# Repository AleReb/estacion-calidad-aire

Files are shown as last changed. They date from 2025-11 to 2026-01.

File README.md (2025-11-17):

# Estación Multiparamétrica de Calidad del Aire

La estación integra sensores **electroquímicos**, **ópticos** y **meteorológicos** en una estructura vertical compacta. El sistema recolecta, almacena y transmite datos **en tiempo casi real**, lo que permite correlacionar calidad del aire y condiciones meteorológicas. Actualmente se encuentra en construcción con pruebas de campo; todos los sensores cuentan con especificaciones validadas y se calibran antes de entrar en operación.

## Características destacadas
- Soporte tipo torre de 2–5 m con exposición 360° y altura de medición a 1,5 m sobre nivel del suelo.
- Alimentación autónoma mediante panel solar y banco de baterías.
- Comunicaciones GSM/4G complementadas con almacenamiento local en microSD.
- Plataforma única con sensores sincronizados y módulos accesibles para reemplazo rápido.
- Incluye colectores para muestreo pasivo de material particulado sedimentable (conforme a Resolución Exenta N° 1449 del MMA, 2023).

## Sensores integrados
| Tipo | Modelo | Rango / Límite | Precisión / Resolución | Tecnología |
| --- | --- | --- | --- | --- |
| PM1.0/2.5/10 | Plantower PMS5003ST | 1 µg/m³ (límite) | ±1 µg/m³ | Óptico láser |
| O₃ | Alphasense OX-B431 | 1 ppb (límite) | ±1 ppbv | Amperométrico |
| NO₂ | Alphasense NO2-B43F | 1 ppb (límite) | ±1 ppbv | Amperométrico |
| CO | Alphasense CO-B4 | 1 ppm (límite) | ±1 ppmv | Amperométrico |
| NO | Alphasense NO-B4 | 1 ppb (límite) | ±1 ppbv | Amperométrico |
| CO₂ | Winsen MH-Z19B/MH-Z19C | 1 ppm (resolución) | — | Infrarrojo NDIR |
| VOC (totales) | Winsen ZE40A-TVOC | 0–2 ppm | 0.01 ppm | PID/MOS |
| SO₂ | Alphasense SO2-B4 (objetivo) | 5 ppb (error) | — | Electroquímico |
| Meteo (T, HR, P, VV, DV, precipitación, radiación, UV, luz) | ComWinTop CWT-UWD-SDTHAPSIR / CWT-UR-S | Según ficha | Ver ficha | RS485 (Modbus) |

## Aplicaciones
- Monitoreo ciudadano y municipal.
- Validación de sensores de bajo costo.
- Correlación con estaciones de referencia.
- Evaluación de impactos urbanos o industriales.

## Guía rápida del repositorio
- `01-requisitos-interesados/`: necesidades y casos de uso basados en el brochure técnico.
- `02-requisitos-sistema/`: requisitos funcionales/no funcionales y especificaciones (contaminantes, soporte meteo, emergentes).
- `03-diseño-arquitectura/`: decisiones, vistas de arquitectura y espacio para diagramas.
- `04-diseño-detallado/`: definición preliminar de hardware, firmware y gestión de datos.
- `05-implementacion/`: árbol para hardware (PCB, carcasas, componentes), firmware (PlatformIO) y software (backend/frontend/scripts).
- `06-10/`: integración, verificación, validación, despliegue y operación/mantenimiento.
- `documentacion/`, `datos/`, `herramientas/`, `configuracion/`: repositorios para datasheets, datasets EPA/WMO, utilidades y perfiles de configuración.
- `gestion-proyecto/planificacion/roles-responsabilidades.md`: lista actualizada de cargos, incluyendo QA/QC y administración de datos.

## Índice de informes y manuales
| Recurso | Ubicación | Descripción |
| --- | --- | --- |
| Manual ISB/AFE y notas de aplicación Alphasense | [`documentacion/datasheets-sensores/sensores-gases/electroquimicos/alphasense/`](documentacion/datasheets-sensores/sensores-gases/electroquimicos/alphasense/) | PDFs AAN-803-05, manual ISB y guía rápida de placas que convierten corriente a voltaje para sensores B4/B43F. |
| Tutorial offsets WEe/AEe | [`documentacion/manuales-tecnicos/calibracion/tutorial-offsets-wee-aee.md`](documentacion/manuales-tecnicos/calibracion/tutorial-offsets-wee-aee.md) | Procedimiento paso a paso para medir offsets electrónicos en placas ISB/AFE con multímetro. |
| Nota técnica AAN-803-05 | [`documentacion/manuales-tecnicos/calibracion/AAN-803-05.pdf`](documentacion/manuales-tecnicos/calibracion/AAN-803-05.pdf) | Referencia oficial del fabricante para calibraciones electroquímicas. |
| Brochure y ficha de operación en terreno | [`documentacion/manuales-tecnicos/operacion/brochure.pdf`](documentacion/manuales-tecnicos/operacion/brochure.pdf) · [`documentacion/manuales-tecnicos/operacion/Ficha Terreno AIRE.pdf`](documentacion/manuales-tecnicos/operacion/Ficha%20Terreno%20AIRE.pdf) | Ficha de despliegue en terreno y brochure visual del proyecto. |
| Reporte laboratorio – voltaje circuito abierto ISB | [`documentacion/informes-pruebas/laboratorio/condiciones-controladas/Volt_Circuito_abierto_ISB_alphasense_est05/Voltage_circuito_abierto_alphasense_estacion_5.pdf`](documentacion/informes-pruebas/laboratorio/condiciones-controladas/Volt_Circuito_abierto_ISB_alphasense_est05/Voltage_circuito_abierto_alphasense_estacion_5.pdf) | Informe LaTeX con fotos e instrumental para medición de voltaje en placas ISB. Incluye fuentes `.tex` e imágenes en `img/`. |
| Reporte campo – co-ubicación SINCA | [`documentacion/informes-pruebas/campo/co-ubicacion-sinca/calibracion-sinca-1.pdf`](documentacion/informes-pruebas/campo/co-ubicacion-sinca/calibracion-sinca-1.pdf) | Evidencia PDF de campaña de co-ubicación para calibraciones con red SINCA. |

## Equipo de trabajo
| Rol | Responsable | Función principal |
| --- | --- | --- |
| Dirección del proyecto | Zoe Fleming | Define lineamientos estratégicos, asegura recursos y relación con interesados de alto nivel. |
| Coordinación general | Luis Gómez | Coordina disciplinas, consolida reportes de avance y comunica el estado del proyecto. |
| Firmware y comunicaciones | Alejandro Rebolledo | Lidera programación de firmware, integración de sensores y enlaces GSM/4G/RS485. |
| Operaciones en terreno | Pablo Ortiz | Gestiona despliegues de torres, logística de instalación y soporte en campo. |
| Mediciones y administración de datos | Catalina Azola | Define rutinas de muestreo, resguarda datos de mediciones y entrega datasets a QA/QC. |
| Documentación regulatoria, QA/QC y bases de datos | Christopher Silva | Mantiene cumplimiento normativo, verifica calidad de datos y gestiona respaldos/registros. |
| Diseño de hardware y componentes | Rodrigo Ortega | Diseña la estructura física, integra panel solar + baterías y define componentes mecánicos. |
| Diseño electrónico | Sebastián Adonay | Desarrolla la electrónica de adquisición y acondicionamiento para sensores electroquímicos, ópticos y meteorológicos. |

## Cómo colaborar (incluye uso con Codex)
1. Clona este repositorio y revisa el README antes de abrir Codex.
2. Abre una sesión de Codex desde la raíz (`codex run`), y revisa los archivos en `gestion-proyecto/planificacion/` para conocer roles y tareas pendientes.
3. Documenta nuevas decisiones en la carpeta correspondiente (por ejemplo, requisitos → `02-...`, hardware → `04-diseño-detallado/...`).
4. Añade contenidos reales en los documentos vacíos; si no existe información todavía, deja una nota explícita indicando que está pendiente (mantén el estilo usado hasta ahora).
5. Usa `.gitkeep` para conservar directorios vacíos si agregas nuevos subcontenidos.
6. Antes de hacer commit, ejecuta `git status` para revisar qué archivos cambiaste y organiza los mensajes de commit por área (requisitos, arquitectura, firmware, etc.).

## Contacto
Proyecto en desarrollo: **Estación Multiparamétrica de Monitoreo Ambiental**  \
Contacto: [luis.gomez@udd.cl](mailto:luis.gomez@udd.cl)

## Descargo de Responsabilidad

El código y la documentación de este proyecto se ofrecen "tal cual", sin garantías de ningún tipo, expresas o implícitas. El uso de este material es bajo su propio riesgo. Los autores no se hacen responsables de ningún daño o pérdida que pueda surgir de su uso.

## Licencia

Este proyecto está licenciado bajo la **Creative Commons Attribution-NonCommercial 4.0 International (CC BY-NC 4.0)**.



Usted es libre de:
-   **Compartir** — copiar y redistribuir el material en cualquier medio o formato.
-   **Adaptar** — remezclar, transformar y construir sobre el material.

Bajo los siguientes términos:
-   **Atribución** — Debe dar crédito de manera adecuada, proporcionar un enlace a la licencia, e indicar si se han realizado cambios.
-   **NoComercial** — No puede utilizar el material para una finalidad comercial.

Para ver una copia de esta licencia, visite [http://creativecommons.org/licenses/by-nc/4.0/](http://creativecommons.org/licenses/by-nc/4.0/) o consulte el archivo [LICENSE](LICENSE) en este repositorio.

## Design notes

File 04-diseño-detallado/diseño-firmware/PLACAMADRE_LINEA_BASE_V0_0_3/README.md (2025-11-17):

# Firmware Placa Madre Línea Base v0.0.3

Este directorio contiene el código fuente del firmware para la placa de monitoreo ambiental "Placa Madre Rev. D", basada en un microcontrolador ESP32.

## Descripción General

El firmware está diseñado para operar como un sistema de monitoreo ambiental autónomo y robusto. Se encarga de recolectar datos de una amplia gama de sensores, almacenarlos localmente en una tarjeta SD y transmitirlos periódicamente a un servidor remoto a través de una red celular (GSM/LTE). Además, integra la capacidad de capturar y enviar imágenes desde una cámara externa.

## Características Principales

-   **Adquisición de Datos Multi-Sensor:** Integra y lee datos de sensores analógicos y digitales a través de I2C, UART y RS485.
-   **Almacenamiento Local:** Guarda todas las mediciones y los registros de errores en formato CSV en una tarjeta SD para redundancia y análisis posterior.
-   **Comunicaciones Celulares:** Utiliza un módem SIM7600 para enviar datos de sensores e imágenes a un servidor web mediante peticiones HTTP (GET y POST).
-   **Gestión de Cámara Externa:** Controla una cámara conectada por puerto serie para solicitar, recibir y almacenar imágenes.
-   **Robustez y Estabilidad:** Implementa un Watchdog Timer (WDT) para reiniciarse automáticamente en caso de bloqueo. Incluye una máquina de estados para reiniciar el módem si falla repetidamente.
-   **Gestión de Energía:** Controla la alimentación de periféricos como la cámara y el módem para optimizar el consumo.
-   **Interfaz de Depuración:** Ofrece un conjunto de comandos a través del puerto serie para facilitar la depuración y el control manual de funciones clave.
-   **Feedback Visual:** Utiliza un LED RGB (NeoPixel) para indicar el estado del sistema (inicio, éxito, error, etc.).

## Hardware y Librerías Clave

-   **Microcontrolador:** ESP32
-   **Módem:** SIMCom SIM7600 (`TinyGsmClient`)
-   **Sensores Analógicos:** Múltiples `Adafruit_ADS1115` para gases (NO₂, CO, O₃, NO, SO₂).
-   **Sensores Digitales:**
    -   `MHZ19` (CO₂) por UART.
    -   `PMS5003` (Material Particulado) por UART.
    -   Estación Meteorológica y Sensor UV por RS485 (`ModbusMaster`).
    -   Sensor TVOC/SO₂ externo por I2C.
-   **Reloj en Tiempo Real:** `RTC_DS3231` para timestamping preciso.
-   **Almacenamiento:** Tarjeta MicroSD.
-   **Cámara:** Dispositivo externo controlado por UART.

## Estructura del Código y Módulos

El proyecto está modularizado en varios archivos `.ino` para una mejor organización:

-   `PLACAMADRE_LINEA_BASE_V0_0_3.ino`: Archivo principal. Contiene la lógica de `setup()` y `loop()`, la inicialización de todos los periféricos y la orquestación de las tareas principales (leer, guardar, enviar).
-   `sensores.ino`: Agrupa todas las funciones dedicadas a la lectura de los diferentes sensores (ADCs, Modbus, I2C, UART).
-   `datalogger.ino`: Gestiona todas las operaciones de escritura en la tarjeta SD, incluyendo la creación de archivos CSV para datos y logs, y la función para añadir registros.
-   `gsm.ino`: Contiene toda la lógica de comunicación con el módem SIM7600. Esto incluye el envío de comandos AT, la conexión a la red GPRS, el envío de datos por HTTP y la máquina de estados para reiniciar el módem.
-   `cam.ino`: Implementa el protocolo de comunicación serie para solicitar y recibir imágenes de la cámara externa, gestionando la recepción por trozos y los reintentos.
-   `rtc.ino`: Funciones para la gestión del reloj DS3231, incluyendo la sincronización de la hora a partir de la red celular.
-   `neopixel.ino`: Controla el LED RGB para proporcionar feedback visual del estado del sistema.
-   `serialComands.ino`: Define una interfaz de comandos a través del monitor serie para depuración.
-   `auxiliar.ino`: Contiene funciones de ayuda, como la que imprime el motivo del último reinicio del ESP32.
-   `web.ino`: (Actualmente desactivado en el código principal) Implementa un servidor web a través de un punto de acceso WiFi para gestionar los archivos de la SD de forma remota.

## Lógica Operacional

El `loop()` principal opera en base a temporizadores no bloqueantes (`millis()`) y una máquina de estados simple controlada por banderas (`bools`):

1.  **Lectura de Sensores (`leyendoDatos`):** Cada 20 segundos, se leen todos los sensores y se actualizan las variables globales.
2.  **Guardado en SD (`savedSD`):** Cada 60 segundos, se construye una línea de CSV con los últimos datos leídos y se guarda en la tarjeta SD.
3.  **Envío de Datos (`sending`):** Cada 5 minutos, se envían los últimos datos al servidor remoto a través de una petición HTTP GET.
4.  **Gestión de Fotos (`requestedfoto`):** Cada 3 horas, se solicita una foto a la cámara, se recibe, se guarda en la SD y se envía al servidor a través de una petición HTTP POST.

## Comandos de Depuración por Puerto Serie

Conectado a 115200 baudios, puedes usar los siguientes comandos:

-   `h`: Muestra la lista de comandos.
-   `s`: Envía la última foto capturada al servidor.
-   `t`: Sincroniza el reloj RTC con la hora de la red celular.
-   `c`: Enciende la cámara y solicita una foto.
-   `d`: Envía los datos de los sensores al servidor.
-   `e`: Inicia un ciclo de reinicio de energía para el módem.
-   `f`: Simula un error de transmisión para probar el contador de fallos del módem.
-   `g`: Realiza un test de la SIM y actualiza la información de la red.

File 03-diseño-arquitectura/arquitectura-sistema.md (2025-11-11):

# Arquitectura del sistema

## Soporte físico
- Torre entre 2 y 5 metros con exposición 360°.
- Altura de medición establecida en 1,5 metros sobre el nivel del suelo.

## Energía
- Alimentación mediante panel solar y banco de baterías para operación autónoma.

## Comunicaciones y almacenamiento
- Transmisión principal por GSM/4G.
- Respaldo local a través de microSD.

## Integración de sensores
- Sensores electroquímicos (Alphasense serie B4/B43F) para O₃, NO₂, CO y NO.
- Sensor óptico láser Plantower PMS5003ST para PM₁.₀, PM₂.₅ y PM₁₀.
- Sensores adicionales: CO₂ (Winsen MH-Z19B/MH-Z19C), VOC totales (Winsen ZE40A-TVOC) y SO₂ (Alphasense SO2-B4, en definición).
- Estación meteorológica digital RS485 (ComWinTop CWT-UWD-SDTHAPSIR y CWT-UR-S).

## Soporte a muestreo pasivo
- Colectores de material particulado sedimentable ajustados a la Resolución Exenta N° 1449 del MMA (2023).

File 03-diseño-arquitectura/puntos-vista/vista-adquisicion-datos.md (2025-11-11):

# Vista de adquisición de datos
- Los sensores están sincronizados en una plataforma única para asegurar series temporales consistentes.
- Los datos se almacenan localmente en microSD y se transmiten por GSM/4G casi en tiempo real.
- La altura de medición (1,5 m) y la torre de 2–5 m mantienen condiciones homogéneas durante la adquisición.

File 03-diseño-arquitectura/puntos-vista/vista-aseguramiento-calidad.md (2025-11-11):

# Vista de aseguramiento de calidad
- Todos los sensores cuentan con especificaciones validadas y se calibran previamente a su operación.
- La estación incluye equipos de muestreo pasivo de material particulado sedimentable conforme a Resolución Exenta N° 1449 (MMA, 2023) para contrastar datos.
- El brochure advierte que CO y SO₂ pueden ubicarse cerca del límite de detección en entornos urbanos; se monitorean para eventos significativos, lo que condiciona los planes de QA/QC.

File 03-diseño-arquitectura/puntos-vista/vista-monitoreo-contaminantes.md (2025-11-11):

# Vista de monitoreo de contaminantes
- Sensores capturan PM₁.₀, PM₂.₅ y PM₁₀ mediante Plantower PMS5003ST (límite 1 µg/m³, precisión ±1 µg/m³).
- Gases criterio O₃, NO₂, CO y NO se monitorean con la serie Alphasense B4/B43F con límites de 1 ppb (1 ppm para CO).
- Los sensores se encuentran en una estructura vertical compacta con exposición 360° para captar eventos urbanos e industriales.

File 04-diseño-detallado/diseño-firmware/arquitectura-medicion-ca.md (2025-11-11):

# Arquitectura de medición de calidad del aire
- El firmware integra lecturas de sensores electroquímicos (O₃, NO₂, CO, NO), ópticos (PM₁.₀/PM₂.₅/PM₁₀) y meteorológicos RS485.
- Todos los canales se sincronizan para entregar datos en tiempo casi real, cumpliendo el objetivo del brochure.

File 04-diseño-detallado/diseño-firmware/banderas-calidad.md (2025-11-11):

# Banderas de calidad
El brochure solo indica que los sensores se calibran previamente y cuentan con especificaciones validadas; no se entregan definiciones de banderas. Esta sección quedará pendiente hasta contar con reglas de QA/QC detalladas.

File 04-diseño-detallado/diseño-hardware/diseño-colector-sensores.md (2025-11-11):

# Diseño del colector de sensores
- Estructura vertical compacta montada en torre de 2–5 m con exposición 360°.
- Módulos accesibles para mantenimiento rápido según la configuración descrita en el brochure.
- Integración física de sensores electroquímicos (Alphasense), ópticos (PMS5003ST) y meteorológicos (ComWinTop RS485) en un solo soporte para garantizar sincronización.

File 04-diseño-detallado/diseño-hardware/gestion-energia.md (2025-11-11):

# Gestión de energía
- Alimentación mediante panel solar con banco de baterías, tal como se declara en la configuración del sistema.
- El esquema autónomo soporta la operación continua del datalogger, las comunicaciones GSM/4G y los sensores meteorológicos RS485.

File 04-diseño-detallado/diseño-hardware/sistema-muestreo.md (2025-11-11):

# Sistema de muestreo
- Altura de captación de 1,5 m sobre nivel del suelo para alinearse con la exposición definida.
- Colectores para material particulado sedimentable compatibles con Resolución Exenta N° 1449 (MMA, 2023).
- Sensores ópticos y electroquímicos ubicados en flujo controlado dentro del colector para mantener la precisión declarada (±1 µg/m³ para PM, ±1 ppbv para O₃/NO₂/NO).

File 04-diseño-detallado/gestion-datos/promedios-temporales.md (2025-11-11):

# Promedios temporales
El material disponible no detalla ventanas de promedio (minutal, horario, diario). Se debe completar cuando se definan los procesos de reporte.

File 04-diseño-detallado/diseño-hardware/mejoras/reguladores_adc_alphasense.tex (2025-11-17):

\documentclass[a4paper, 12pt]{article}

% --- PAQUETES BÁSICOS ---
\usepackage[utf8]{inputenc}
\usepackage[T1]{fontenc}
\usepackage[spanish]{babel} % Para soporte de idioma español
\usepackage{amsmath} % Para símbolos matemáticos (ge, mu, le, approx, etc.)
\usepackage{amssymb} % Para más símbolos
\usepackage[margin=1in]{geometry} % Para márgenes
\usepackage{textcomp} % Para I²C
\usepackage{graphicx} % Para imágenes (aunque no se usan aquí)

% --- PAQUETE DE HIPERVÍNCULOS ---
\usepackage{hyperref}
\hypersetup{
    colorlinks=true,
    linkcolor=blue,
    filecolor=magenta,      
    urlcolor=blue, % Color de los links
    pdftitle={Reguladores de alto PSRR y ADC de alta resolución para sensores Alphasense},
    pdfpagemode=FullScreen,
}

% --- TÍTULO ---
\title{Reguladores de alto PSRR y ADC de alta resolución para sensores Alphasense}
\author{} % Ocultar autor
\date{} % Ocultar fecha

% --- INICIO DEL DOCUMENTO ---
\begin{document}

\maketitle

Para obtener mediciones precisas con sensores de gas electroquímicos Alphasense (ej. OX-B431, NO2-B43F), es crucial proporcionarles una alimentación muy estable y leer su salida analógica con suficiente resolución.

A continuación se presentan opciones de reguladores lineales de alto rechazo de ruido (PSRR) para filtrar el ruido de la fuente de 5V/12V (proveniente de conversión DC-DC), junto con convertidores ADC de $\ge 12$ bits de resolución, de bajo ruido y con interfaz digital (I²C/SPI) adecuadas para las salidas analógicas de estos sensores.

\section*{Reguladores lineales de alto PSRR y bajo ruido}

Los siguientes reguladores ofrecen alto rechazo de rizado ($>70$dB) en frecuencias medias/altas y baja interferencia, facilitando una alimentación limpia (3.5-6.4 V DC) para las placas acondicionadoras (ISB) de los sensores Alphasense\textsuperscript{1, 2}. Todos son componentes compactos (montaje en PCB) con documentación disponible, y muchos se pueden encontrar en AliExpress u otras tiendas:

\begin{itemize}
    \item \textbf{Microchip MCP1754/MCP1755} Regulador CMOS LDO de 150 mA, rango de entrada 3.6-16V y salida fija o ajustable hasta 5.5 V. Destaca por PSRR $>70$ dB @1 kHz\textsuperscript{3} y baja corriente quiescente ($\sim 56~\mu$A). Dropout típico de 300 mV @150 mA, con ruido de salida muy bajo. Disponible en encapsulados SOT-23, SOT-223, etc., fácil de integrar\textsuperscript{4}. Precio aprox. $< 1$ USD por unidad.

    \item \textbf{Diodes Inc. AP7387} Nueva familia de LDO 5-60 V in, 150 mA out. Combina PSRR $\sim 70$ dB @1 kHz con ultra bajo consumo (2 $\mu$A)\textsuperscript{5}. Viene en versiones de salida fija comunes (3.3V, 5.0V, etc., $\pm 2\%$ precisión)\textsuperscript{6}. Ideal para alimentar desde baterías de 12V o 24V, minimizando el ruido de conversores previos. Encapsulados SOT23/SOT89 (de 3 a 5 pines), muy compactos y económicos ($\sim 0,3$ USD en volúmenes\textsuperscript{7}).

    \item \textbf{STMicroelectronics LDO40L} LDO automotriz 38 V max in, 400 mA out. Posee PSRR de 70 dB @1 kHz y ruido ultra bajo ($\sim 20~\mu\text{V}_{\text{RMS}}$ referido a Vout)\textsuperscript{8}. Soporta salida fija (3.3V, 5V, etc.) o ajustable hasta 11V, con dropout $\le 140$ mV @400 mA\textsuperscript{9}. Encapsulado DFN6 (3x3 mm). Aunque requiere cuidado de soldado, ofrece alta estabilidad y protección interna (limitación de corriente y térmica)\textsuperscript{8}. Aprox. 1-2 USD.

    \item \textbf{TI TPS7A4700/TPS7A47} - Regulador LDO ultra bajo ruido de Texas Instruments, soporta entrada hasta 36 V, salida 1.4-20V (1 A máx). Ofrece solo $4~\mu\text{V}_{\text{RMS}}$ de ruido en banda 10-100 kHz\textsuperscript{10} y mantiene PSRR alto ($\approx 78$ dB @1 kHz) e incluso $\sim 74$ dB a 1 MHz\textsuperscript{11}. Incluye filtro de ruido (pin NR) para optimizar la limpieza de salida. Viene en QFN-20 o MSOP-8 exponenciado; es un componente profesional (usado en instrumentación de alta precisión y audio)\textsuperscript{12}. Precio ~3-5 USD. Recomendado si se busca máxima filtración de ruido de conmutación.

    \item \textbf{Analog Devices LT3042} - LDO de referencia para aplicaciones RF/análogas sensibles. Entrada 1.8-20 V, salida hasta 15V (200 mA). Presenta PSRR excepcional ($\approx 79$dB @1MHz) y ruido ínfimo ($\sim 0.8~\mu\text{V}_{\text{RMS}}$) gracias a su arquitectura de alta ganancia\textsuperscript{11}. Requiere pocos componentes externos (resistor de programación y capacitores), pero viene en MSOP/DFN de 10 pines. Es viable para lograr una línea de 5 V muy limpia a partir de 12V con carga ligera (los módulos ISB consumen $\sim 1$ mA cada uno\textsuperscript{13, 14}). Su disponibilidad puede ser limitada, pero hay módulos en AliExpress que incorporan el LT3042 listos para usar (orientados a audio Hi-Fi), alrededor de 10-15 USD.
\end{itemize}

Nota: Se debe evitar el uso de reguladores comunes como LM7805, LM317 o AMS1117 para esta aplicación sin filtros adicionales, ya que su PSRR cae en frecuencias altas, pudiendo dejar pasar ruido de switching. Los reguladores anteriores destacan por mantener un rechazo elevado más allá de la región audible, asegurando que el ruido del convertidor DC-DC (ej. rizado de cientos de kHz) no introduzca variaciones en la señal del sensor. Asimismo, se recomienda agregar capacitores de filtrado de alta frecuencia (cerámicos de 0.1 $\mu$F cerca de la entrada/salida) e incluso filtros $\pi$ o LC si el ruido de la fuente es muy agresivo.

\section*{ADCs de alta resolución y bajo ruido $(I^2C/SPI)$}

Las salidas analógicas de los sensores Alphasense (a través del tablero ISB) son señales de muy baja amplitud y pueden variar solo unos pocos milivoltios o menos según la concentración de gas. Para capturarlas con precisión, se requieren ADC externos de alta resolución ($\ge 12$ bits) y bajo nivel de ruido. A continuación, algunas opciones populares (disponibles como chips o módulos en AliExpress) para leer estas señales, idealmente en configuración diferencial (para restar el electrodo auxiliar) y con interfaz digital sencilla:

\begin{itemize}
    \item \textbf{Texas Instruments ADS1115} - ADC 16 bits, 4 canales (o 2 diferenciales) con I²C. Es ampliamente utilizado por su facilidad y precisión: proporciona 16-bit efectivos hasta 860 muestras/segundo vía I²C\textsuperscript{15}. Incluye PGA programable (ganancia hasta x16) para amplificar señales débiles y aprovechar todo el rango\textsuperscript{15}. Opera entre 2.0-5.5 V. Es perfecto para estos sensores - de hecho, se emplea en placas comerciales para Alphasense (Smart Citizen Kit) para leer múltiples sensores de gas\textsuperscript{16, 17}. Se consigue como módulo de 4 canales ($\sim 3-5$ USD en marketplaces) o en IC SSOP. Su ruido interno es bajo: a ganancia máxima ($\pm 0.256$ V rango) cada bit $\approx 7.8~\mu$V, logrando 15 bits libres de ruido a baja velocidad\textsuperscript{18, 19}, suficiente para resolver variaciones de pocos ppb en concentración.

    \item \textbf{Microchip MCP3424} Convertidor Delta-Sigma de 18 bits, 4 canales diferencial (I²C). Ofrece resolución seleccionable (12/14/16/18 bits) y velocidades de conversión de 240 SPS (12-bit) hasta 3.75 SPS (18-bit)\textsuperscript{20}. Incluye un PGA de x1-x8 y autocalibración interna de offset/ganancia en cada conversión\textsuperscript{21}, útil para medir señales muy débiles con alta exactitud. Funciona de 2.7-5.5V. Es reconocido como ADC de "bajo ruido y alta precisión" dentro de su familia\textsuperscript{21}. Disponible en módulos breakout (ej. DFRobot Fermion, alrededor de 10-15 USD) y también en versiones de 2 canales (MCP3422) si se requieren menos entradas. Ideal cuando se busca mayor resolución que 16-bit a costo razonable.

    \item \textbf{TI / Waveshare ADS1256} ADC 24 bits, 8 canales (SPI) para quienes necesiten la máxima resolución. Es un ADC sigma-delta de alta precisión con referencia interna de 2.5 V, muy utilizado en placas de adquisición de datos. Soporta hasta 30 kSPS de salida y puede configurarse en 8 entradas sencillas o 4 diferenciales\textsuperscript{22, 23}. A 24 bits puede resolver microvoltios, capturando incluso fluctuaciones muy pequeñas de la señal del sensor. Funciona a 5 V e incluye un regulador de referencia de bajo ruido (ADR03) en las placas comerciales\textsuperscript{24}. Módulos basados en ADS1256 se encuentran en AliExpress/Amazon ($\sim 20$ USD) ya montados, con interfaz SPI lista para conectar a un microcontrolador. Son adecuados si se requiere registrar niveles de ppb con mínima incertidumbre, aunque implican más complejidad de software y consumo.

    \item \textbf{Otras opciones:} Si el presupuesto o la complejidad son factores, existen ADCs más sencillos de 12-16 bits que pueden servir. Por ejemplo, el ADS1015 (hermano menor del ADS1115, 12 bits a 3.3 kSPS, I²C) o los MCP3008/MCP3208 (SAR ADC de 10/12 bits, SPI de 8 canales). No ofrecen el mismo nivel de ruido ultra-bajo que los sigma-delta anteriores, pero pueden ser suficientes para aplicaciones menos exigentes.
\end{itemize}

En general, para sensores de gases traza donde las variaciones de señal son muy pequeñas, conviene priorizar ADC de sigma-delta con alta resolución y filtrado digital, incluso si su velocidad es menor, ya que los sensores Alphasense tienen respuesta en escala de segundos.

Referencias específicas: Alphasense recomienda un diseño de electrónica de bajo ruido para alcanzar resoluciones de 15 ppb\textsuperscript{25, 2}. Por ello, combinar un buen regulador LDO (como los anteriores) - que asegure una alimentación de 5V limpia y estable para la placa ISB junto con un ADC de alta resolución ($16+$ bits) por I²C/SPI, permitirá explotar al máximo la precisión de estos sensores. En la práctica, desarrollos como la placa Smart Citizen ASB utilizan dos ADS1115 de 16-bit para leer hasta 8 canales analógicos Alphasense\textsuperscript{16, 17}, demostrando la viabilidad de estas soluciones con componentes disponibles en el mercado.

Cada componente mencionado incluye documentación detallada del fabricante y suele estar disponible en plataformas como AliExpress, eBay o distribuidores (a veces como módulos listos para usar), facilitando su integración en un diseño personalizado.

\section*{Referencias}

\begin{itemize}
    \item \href{https://www.isweek.com/product/individual-sensor-board-isb-alphasense-b4-4-electrode-gas-sensors-isb_51.html}{1 2 13 14 Individual Sensor Board (ISB) Alphasense B4 4-Electrode Gas Sensors - ISB}
    \item \href{https://ww1.microchip.com/downloads/aemDocuments/documents/APID/ProductDocuments/DataSheets/MCP1754-and-MCP17545-Data-Sheet-DS20002276.pdf}{4 MCP1754/MCP1754S Data Sheet}
    \item \href{https://www.diodes.com/about/news/press-releases/60v-70db-psrr-Idos-from-diodes-incorporated-deliver-industry-leading-quiescerit-current}{5 6 7 60V, 70dB PSRR LDOs from Diodes Incorporated Deliver Industry-Leading Quiescent Current}
    \item \href{https://www.st.com/resource/en/datasheet/Ido40l.pdf}{9 Datasheet - LDO40L - 400 mA, 38 V low-dropout regulator, with 45 µA quiescent current}
    \item \href{https://www.ti.com/lit/gpn/TPS7A47}{10 TPS7A470x 36-V, 1-A, 4-µVRMS, RF LDO Voltage Regulator datasheet (Rev. F)}
    \item \href{https://www.analog.com/media/en/technical-documentation/data-sheets/3042fb.pdf}{11 [PDF] LT3042-20V, 200mA, Ultralow Noise, Ultrahigh PSRR RF Linear ...}
    \item \href{https://www.diyaudio.com/community/threads/new-Idovr-com-power-modules-it3045-lt3094-tps7a4700-tps7a3301.381199/}{12 New Idovr.com power modules (LT3045/LT3094/TPS7A4700 ...}
    \item \href{https://www.adafruit.com/product/1085?srsltid=AfmBOopx0wbvB1RWUhtVSYuXBsSMYawmOMs_8VuhxXXwaKvWz0Q7wUeQ}{15 ADS1115 16-Bit ADC-4 Channel with Programmable Gain Amplifier [STEMMA QT/Qwiic]: ID 1085: Adafruit Industries, Unique \& fun DIY electronics and kits}
    \item \href{https://docs.smartcitizen.me/hardware/boards/analog-sensor-board/}{16: 17 Analog Sensor Board - Smart Citizen Docs}
    \item \href{https://www.ti.com/lit/ds/symlink/ads1115.pdf}{18 19 ADS111x Ultra-Small, Low-Power, I2 C-Compatible, 860SPS, 16-Bit ADCs with Internal Reference, Oscillator, and Programmable Comparator datasheet (Rev. E)}
    \item \href{https://www.dfrobot.com/product-1182.html?srsltid=AfmBOoqQvFr-aAvIAWsH3YGbETrjZec9XZqxHzjl9ZRzbmjEL9ZKml76}{20 21 Fermion: MCP3424 18-Bit ADC-4 Channel with Programmable Gain Amplifier - DFRobot}
    \item \href{https://www.amazon.com/Channel-ADS1256-Acquisition-Collecting-Precision/dp/B0DBSWRQZS}{22 23 24 24 Bit 8 Channel ADS1256 ADC Data Acquisition Board Module AD Collecting Data Acquisition Card High Precision: Amazon.com: Industrial \& Scientific}
    \item \href{https://www.isweek.com/Uploads/20161216/5853470876f70.pdf}{25 TDS OX-B431 Apr 16.pmd}
\end{itemize}

\end{document}

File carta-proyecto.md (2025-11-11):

# Carta del Proyecto

## Título
**Estación Multiparamétrica de Calidad del Aire** – Brochure técnico.

## Contexto y estado
La estación integra sensores electroquímicos, ópticos y meteorológicos en una estructura vertical compacta. Recolecta, almacena y transmite datos en tiempo casi real, habilitando el análisis conjunto de contaminantes criterio y condiciones meteorológicas. El proyecto se encuentra en fase de construcción con pruebas de campo; los sensores tienen especificaciones validadas y se calibran antes de operar.

## Configuración del sistema
- Soporte: torre entre 2 y 5 metros con exposición 360° y altura de medición en 1,5 metros.
- Energía: panel solar complementado con banco de baterías para operación autónoma.
- Comunicaciones: enlace GSM/4G y respaldo local mediante microSD.
- Integración: plataforma única con sincronización de sensores y módulos desmontables para mantenimiento rápido.

## Sensores incluidos
### Material particulado
- Plantower PMS5003ST para PM₁.₀, PM₂.₅ y PM₁₀ (límite 1 µg/m³, precisión ±1 µg/m³, tecnología óptica láser).

### Gases criterio (Alphasense serie B4/B43F)
- O₃: modelo OX-B431 (límite 1 ppb, precisión ±1 ppbv, cartucho combinado O₃/NO₂).
- NO₂: modelo NO2-B43F (límite 1 ppb, precisión ±1 ppbv, filtro químico contra O₃).
- CO: modelo CO-B4 (límite 1 ppm, precisión ±1 ppmv, baja deriva).
- NO: modelo NO-B4 (límite 1 ppb, precisión ±1 ppbv, respuesta rápida).

### Gases adicionales
- CO₂: Winsen MH-Z19B/MH-Z19C (NDIR, resolución 1 ppm).
- SO₂: por definir, electroquímico, objetivo 100 ppb.
- COV totales: por definir, PID o MOS, objetivo 1 ppm.

### Sensores meteorológicos
- Estación digital multiparámetro RS485 (Modbus) con temperatura, humedad relativa, presión, velocidad y dirección de viento, precipitación, radiación solar, iluminación e índice UV (ComWinTop CWT-UWD-SDTHAPSIR y CWT-UR-S).

### Otros elementos
- Equipos de muestreo pasivo para material particulado sedimentable, alineados con la Resolución Exenta N° 1449 (MMA, 2023).

## Aplicaciones declaradas
- Monitoreo ciudadano y municipal.
- Validación de sensores de bajo costo.
- Correlación con estaciones de referencia.
- Evaluación de impacto urbano e industrial.

## Contacto
Proyecto en desarrollo: Estación Multiparamétrica de Monitoreo Ambiental.  \
Correo: [luis.gomez@udd.cl](mailto:luis.gomez@udd.cl)

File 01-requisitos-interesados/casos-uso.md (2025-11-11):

# Casos de uso

## CU-01: Monitoreo ciudadano y municipal
- **Actor principal:** Programas municipales de calidad del aire.
- **Objetivo:** Obtener datos continuos de contaminantes y variables meteorológicas en una única plataforma.
- **Resumen:** La estación se instala en una torre de 2–5 m, opera con panel solar + baterías y envía datos por GSM/4G con respaldo en microSD.

## CU-02: Validación de sensores de bajo costo
- **Actor principal:** Equipos de QA/QC.
- **Objetivo:** Comparar lecturas de sensores de bajo costo contra los sensores electroquímicos y ópticos calibrados de la estación.
- **Resumen:** Los sensores cuentan con especificaciones validadas y se calibran antes de operar, permitiendo establecer referencias en tiempo casi real.

## CU-03: Correlación con estaciones de referencia
- **Actor principal:** Investigadores o agencias ambientales.
- **Objetivo:** Analizar el comportamiento de contaminantes criterio frente a datos oficiales de referencia.
- **Resumen:** El sistema transmite datos casi en tiempo real y mantiene almacenamiento local, facilitando la comparación histórica.

## CU-04: Evaluación de impacto urbano/industrial
- **Actor principal:** Evaluadores ambientales.
- **Objetivo:** Medir eventos significativos (por ejemplo CO y SO₂ por sobre sus límites de detección) junto con variables meteorológicas RS485 (Modbus).
- **Resumen:** La integración de sensores sincronizados y los equipos de muestreo pasivo permiten caracterizar eventos urbanos o industriales.

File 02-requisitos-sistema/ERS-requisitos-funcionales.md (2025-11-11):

# ERS – Requisitos funcionales
Los requisitos provienen directamente del brochure técnico.

1. El sistema debe integrar sensores electroquímicos, ópticos y meteorológicos dentro de la misma estructura vertical.
2. Debe recolectar, almacenar y transmitir datos en tiempo casi real.
3. Debe operar con una torre de 2–5 m que asegure exposición 360° y altura de medición a 1,5 m sobre el suelo.
4. Debe incorporar un módulo de comunicaciones GSM/4G y registrar los datos en una memoria microSD local.
5. Los sensores deben sincronizarse en una plataforma única para permitir análisis conjunto.
6. El hardware debe permitir acceso rápido a los módulos para mantenimiento y reemplazos.
7. Debe incluir sensores de material particulado (PMS5003ST), gases criterio (Alphasense serie B4/B43F), CO₂ (Winsen MH-Z19B/MH-Z19C), VOC (Winsen ZE40A-TVOC), SO₂ (Alphasense SO2-B4) y sensores meteorológicos RS485 (ComWinTop CWT-UWD-SDTHAPSIR, CWT-UR-S).
8. Debe soportar equipos de muestreo pasivo para material particulado sedimentable conforme a la Resolución Exenta N° 1449 (MMA, 2023).
9. Debe permitir aplicaciones de monitoreo ciudadano, validación de sensores de bajo costo, correlación con estaciones de referencia y evaluación de impactos urbanos/industriales.

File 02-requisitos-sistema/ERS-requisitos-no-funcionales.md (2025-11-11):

# ERS – Requisitos no funcionales
Valores tomados del brochure técnico.

| Categoría | Requisito | Fuente |
| --- | --- | --- |
| Medición de PM | El sensor Plantower PMS5003ST debe ofrecer límite de detección de 1 µg/m³ y precisión ±1 µg/m³ para PM₁.₀, PM₂.₅ y PM₁₀ mediante tecnología óptica láser. | Sección “Material particulado”. |
| Gases criterio | Los sensores Alphasense OX-B431, NO2-B43F, CO-B4 y NO-B4 deben cumplir límites de detección de 1 ppb (1 ppm para CO) con precisión ±1 ppbv (±1 ppmv para CO). | Sección “Gases criterio”. |
| Gases adicionales | El sensor CO₂ (Winsen MH-Z19B/MH-Z19C) debe entregar resolución de 1 ppm; los sensores SO₂ y COV totales tienen metas de 100 ppb y 1 ppm respectivamente. | Sección “Gases adicionales”. |
| Meteorológicos | La estación digital RS485 (Modbus) debe medir temperatura, humedad relativa, presión, velocidad y dirección del viento, además de variables opcionales (precipitación, radiación, luz, UV) tal como declara el fabricante ComWinTop. | Sección “Sensores meteorológicos” y tabla técnica. |
| Integración de datos | Los sensores deben estar sincronizados y operar en plataforma única para disponibilidad en tiempo casi real. | Descripción general. |
| Fiabilidad | Todos los sensores deben contar con especificaciones validadas y ser calibrados antes de entrar en operación. | Descripción general. |

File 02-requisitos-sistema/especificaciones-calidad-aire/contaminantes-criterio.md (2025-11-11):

# Especificaciones – Contaminantes criterio
Información tomada de las tarjetas “Material particulado” y “Gases criterio — Alphasense serie B4/B43F”.

## Material particulado
| Parámetro | Sensor | Límite de detección | Precisión | Tecnología |
| --- | --- | --- | --- | --- |
| PM₁.₀ / PM₂.₅ / PM₁₀ | Plantower PMS5003ST | 1 µg/m³ | ±1 µg/m³ | Óptico láser |

## Gases criterio (Alphasense B4/B43F)
| Gas | Modelo | Límite de detección | Precisión | Comentario |
| --- | --- | --- | --- | --- |
| O₃ | OX-B431 | 1 ppb | ±1 ppbv | Cartucho combinado O₃/NO₂ (anillo dorado). |
| NO₂ | NO2-B43F | 1 ppb | ±1 ppbv | Filtro químico que suprime interferencia de O₃. |
| CO | CO-B4 | 1 ppm | ±1 ppmv | Adecuado para eventos altos con baja deriva. |
| NO | NO-B4 | 1 ppb | ±1 ppbv | Respuesta rápida y linealidad en ppb. |

> Nota: En contexto urbano típico los canales de CO y SO₂ pueden operar cerca del límite de detección; se priorizan eventos significativos.

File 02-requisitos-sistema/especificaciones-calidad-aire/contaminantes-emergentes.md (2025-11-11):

# Contaminantes emergentes y adicionales

| Parámetro | Sensor | Tecnología | Resolución / objetivo |
| --- | --- | --- | --- |
| CO₂ | Winsen MH-Z19B / MH-Z19C | Infrarrojo NDIR | 1 ppm |
| SO₂ | Alphasense SO2-B4 (por definir) | Electroquímico | 100 ppb (objetivo) |
| COV totales | Winsen ZE40A-TVOC (por definir PID/MOS) | PID o MOS | 1 ppm (objetivo) |

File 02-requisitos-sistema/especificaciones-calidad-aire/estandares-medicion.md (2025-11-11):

# Estándares de medición
El material proporcionado (brochure técnico) no detalla aún métodos EPA, EN o ISO asociados a los sensores. Se deja constancia de que la información deberá incorporarse cuando se disponga de la referencia oficial.

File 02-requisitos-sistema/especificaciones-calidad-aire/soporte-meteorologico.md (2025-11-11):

# Soporte meteorológico para calidad del aire

- Estación digital multiparámetro RS485 (Modbus) que entrega temperatura, humedad relativa, presión, velocidad y dirección del viento.
- Variables adicionales declaradas por el fabricante ComWinTop CWT-UWD-SDTHAPSIR/CWT-UR-S: precipitación, radiación solar, iluminación e índice UV.
- Integración con la misma plataforma de adquisición para mantener sincronía con los sensores de contaminantes y habilitar análisis conjunto.

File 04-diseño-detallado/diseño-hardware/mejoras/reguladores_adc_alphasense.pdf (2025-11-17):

## Reguladores de alto PSRR y ADC de alta resolución para sensores Alphasense

Para obtener mediciones precisas con sensores de gas electroquímicos Alphasense (ej. OX-B431, NO2-B43F), es crucial proporcionarles una alimentación muy estable y leer su salida analógica con suciente resolución.
A continuación se presentan opciones de reguladores lineales de alto rechazo de ruido (PSRR) para ltrar el ruido de la fuente de 5V/12V (proveniente de conversión DC-DC), junto con convertidores ADC de ≥ 12 bits de resolución, de bajo ruido y con interfaz digital (I²C/SPI) adecuadas para las salidas analógicas de estos sensores.

## Reguladores lineales de alto PSRR y bajo ruido

Los siguientes reguladores ofrecen alto rechazo de rizado (> 70dB) en frecuencias medias/altas y baja interferencia, facilitando una alimentación limpia (3.5-6.4 V DC) para las placas acondicionadoras (ISB) de los sensores Alphasense¹, 2. Todos son componentes compactos (montaje en PCB) con documentación disponible, y muchos se pueden encontrar en AliExpress u otras tiendas:

Microchip MCP1754/MCP1755 Regulador CMOS LDO de 150 mA, rango de entrada 3.6-16V y salida ja o ajustable hasta 5.5 V. Destaca por PSRR > 70 dB @1 kHz³ y baja corriente quiescente (∼ 56 µA). Dropout típico de 300 mV @150 mA, con ruido de salida muy bajo. Disponible en encapsulados SOT-23, SOT-223, etc., fácil de integrar⁴
. Precio aprox. < 1 USD por unidad.

Diodes Inc. AP7387 Nueva familia de LDO 5-60 V in, 150 mA out. Combina PSRR ∼ 70 dB @1 kHz con ultra bajo consumo (2 µA)⁵
. Viene en versiones de
salida ja comunes (3.3V, 5.0V, etc., ±2 % precisión)⁶
. Ideal para alimentar desde baterías de 12V o 24V, minimizando el ruido de conversores previos. Encapsulados SOT23/SOT89 (de 3 a 5 pines), muy compactos y económicos (∼ 0, 3 USD en volúmenes⁷
).

STMicroelectronics LDO40L LDO automotriz 38 V max in, 400 mA out. Posee PSRR de 70 dB @1 kHz y ruido ultra bajo (∼ 20 µVRMS referido a Vout)⁸
. Soporta
salida ja (3.3V, 5V, etc.) o ajustable hasta 11V, con dropout ≤ 140 mV @400 mA⁹
. Encapsulado DFN6 (3x3 mm). Aunque requiere cuidado de soldado, ofrece alta estabilidad y protección interna (limitación de corriente y térmica)⁸
. Aprox.
1-2 USD.

TI TPS7A4700/TPS7A47 - Regulador LDO ultra bajo ruido de Texas Instruments, soporta entrada hasta 36 V, salida 1.4-20V (1 A máx). Ofrece solo 4 µVRMS de ruido en banda 10-100 kHz¹⁰ y mantiene PSRR alto (≈ 78 dB @1 kHz) e incluso ∼ 74 dB a 1 MHz¹¹. Incluye ltro de ruido (pin NR) para optimizar la limpieza de salida. Viene en QFN-20 o MSOP-8 exponenciado; es un componente profesional (usado en instrumentación de alta precisión y audio)¹². Precio 3-5 USD. Recomendado si se busca máxima ltración de ruido de conmutación.

Analog Devices LT3042 - LDO de referencia para aplicaciones RF/análogas sensibles. Entrada 1.8-20 V, salida hasta 15V (200 mA). Presenta PSRR excepcional (≈ 79dB @1MHz) y ruido ínmo (∼ 0,8 µVRMS) gracias a su arquitectura de alta ganancia¹¹. Requiere pocos componentes externos (resistor de programación y capacitores), pero viene en MSOP/DFN de 10 pines. Es viable para lograr una línea de 5 V muy limpia a partir de 12V con carga ligera (los módulos ISB consumen ∼ 1 mA cada uno¹³, 14). Su disponibilidad puede ser limitada, pero hay módulos en AliExpress que incorporan el LT3042 listos para usar (orientados a audio Hi-Fi), alrededor de 10-15 USD.

Nota: Se debe evitar el uso de reguladores comunes como LM7805, LM317 o AMS1117 para esta aplicación sin ltros adicionales, ya que su PSRR cae en frecuencias altas, pudiendo dejar pasar ruido de switching. Los reguladores anteriores destacan por mantener un rechazo elevado más allá de la región audible, asegurando que el ruido del convertidor DC-DC (ej. rizado de cientos de kHz) no introduzca variaciones en la señal del sensor. Asimismo, se recomienda agregar capacitores de ltrado de alta frecuencia (cerámicos de 0.1 µF cerca de la entrada/salida) e incluso ltros π o LC si el ruido de la fuente es muy agresivo.

## ADCs de alta resolución y bajo ruido (I

## 2C/SP I)

Las salidas analógicas de los sensores Alphasense (a través del tablero ISB) son señales de muy baja amplitud y pueden variar solo unos pocos milivoltios o menos según la concentración de gas. Para capturarlas con precisión, se requieren ADC externos de alta resolución (≥ 12 bits) y bajo nivel de ruido. A continuación, algunas opciones populares (disponibles como chips o módulos en AliExpress) para leer estas señales, idealmente en conguración diferencial (para restar el electrodo auxiliar) y con interfaz digital sencilla:

Texas Instruments ADS1115 - ADC 16 bits, 4 canales (o 2 diferenciales) con I²C. Es ampliamente utilizado por su facilidad y precisión: proporciona 16-bit efectivos hasta 860 muestras/segundo vía I²C

15. Incluye PGA programable (ganancia hasta x16) para amplicar señales débiles y aprovechar todo el rango¹⁵. Opera entre 2.0-5.5
V. Es perfecto para estos sensores - de hecho, se emplea en placas comerciales para Alphasense (Smart Citizen Kit) para leer múltiples sensores de gas¹⁶, 17. Se consigue como módulo de 4 canales (∼ 3 − 5 USD en marketplaces) o en IC SSOP. Su ruido interno es bajo: a ganancia máxima (±0,256 V rango) cada bit ≈ 7,8 µV, logrando 15 bits libres de ruido a baja velocidad¹⁸, 19, suciente para resolver variaciones de pocos ppb en concentración.

Microchip MCP3424 Convertidor Delta-Sigma de 18 bits, 4 canales diferencial (I²C). Ofrece resolución seleccionable (12/14/16/18 bits) y velocidades de conversión de 240 SPS (12-bit) hasta 3.75 SPS (18-bit)²⁰. Incluye un PGA de x1-x8 y autocalibración interna de oset/ganancia en cada conversión²¹, útil para medir señales muy débiles con alta exactitud. Funciona de 2.7-5.5V. Es reconocido como ADC de "bajo ruido y alta precisión"dentro de su familia²¹. Disponible en módulos breakout (ej. DFRobot Fermion, alrededor de 10-15 USD) y también en versiones de 2 canales (MCP3422) si se requieren menos entradas. Ideal cuando se busca mayor resolución que 16-bit a costo razonable.

TI / Waveshare ADS1256 ADC 24 bits, 8 canales (SPI) para quienes necesiten la máxima resolución. Es un ADC sigma-delta de alta precisión con referencia interna de 2.5 V, muy utilizado en placas de adquisición de datos. Soporta hasta 30 kSPS de salida y puede congurarse en 8 entradas sencillas o 4 diferenciales²², 23. A 24 bits puede resolver microvoltios, capturando incluso uctuaciones muy pequeñas de la señal del sensor. Funciona a 5 V e incluye un regulador de referencia de bajo ruido (ADR03) en las placas comerciales²⁴. Módulos basados en ADS1256 se encuentran en AliExpress/Amazon (∼ 20 USD) ya montados, con interfaz SPI lista para conectar a un microcontrolador. Son adecuados si se requiere registrar niveles de ppb con mínima incertidumbre, aunque implican más complejidad de software y consumo.

Otras opciones: Si el presupuesto o la complejidad son factores, existen ADCs más sencillos de 12-16 bits que pueden servir. Por ejemplo, el ADS1015 (hermano menor del ADS1115, 12 bits a 3.3 kSPS, I²C) o los MCP3008/MCP3208 (SAR ADC de 10/12 bits, SPI de 8 canales). No ofrecen el mismo nivel de ruido ultrabajo que los sigma-delta anteriores, pero pueden ser sucientes para aplicaciones menos exigentes.

En general, para sensores de gases traza donde las variaciones de señal son muy pequeñas, conviene priorizar ADC de sigma-delta con alta resolución y ltrado digital, incluso si su velocidad es menor, ya que los sensores Alphasense tienen respuesta en escala de segundos.
Referencias especícas: Alphasense recomienda un diseño de electrónica de bajo ruido para alcanzar resoluciones de 15 ppb²⁵, 2. Por ello, combinar un buen regulador LDO (como los anteriores) - que asegure una alimentación de 5V limpia y estable para la placa ISB junto con un ADC de alta resolución (16+ bits) por I²C/SPI, permitirá explotar al máximo la precisión de estos sensores. En la práctica, desarrollos como la placa Smart Citizen ASB utilizan dos ADS1115 de 16-bit para leer hasta 8 canales analógicos Alphasense¹⁶, 17 ,
demostrando la viabilidad de estas soluciones con componentes disponibles en el mercado. Cada componente mencionado incluye documentación detallada del fabricante y suele estar disponible en plataformas como AliExpress, eBay o distribuidores (a veces como módulos listos para usar), facilitando su integración en un diseño personalizado.

## Referencias

1 2 13 14 Individual Sensor Board (ISB) Alphasense B4 4-Electrode Gas Sensors -ISB (https://www.isweek.com/product/individual-sensor-board-isb-alphasense-b4-4-electrode-gas-sensors-isb_51.html)

4 MCP1754/MCP1754S Data Sheet (https://ww1.microchip.com/downloads/aemDocuments/documents/APID/ProductDocuments/DataSheets/MCP1754-and-MCP17545-Data-Sheet-DS20002276.pdf)

5 6 7 60V, 70dB PSRR LDOs from Diodes Incorporated Deliver Industry-Leading Quiescent Current (https://www.diodes.com/about/news/press-releases/60v-70db-psrr-Idos-from-diodes-incorporated-deliver-industry-leading-quiescerit-current)

9 Datasheet - LDO40L - 400 mA, 38 V low-dropout regulator, with 45 µA quiescent current (https://www.st.com/resource/en/datasheet/Ido40l.pdf)

10 TPS7A470x 36-V, 1-A, 4-µVRMS, RF LDO Voltage Regulator datasheet (Rev.
F) (https://www.ti.com/lit/gpn/TPS7A47)

11 [PDF] LT3042-20V, 200mA, Ultralow Noise, Ultrahigh PSRR RF Linear ... (https://www.analog.com/media/en/technical-documentation/data-sheets/3042fb.pdf)

12 New Idovr.com power modules (LT3045/LT3094/TPS7A4700 ... (https://www.diyaudio.com/community/threads/new-Idovr-com-power-modules-it3045-lt3094-tps7a4700-tps7a3301.381199/)

15 ADS1115 16-Bit ADC-4 Channel with Programmable Gain Amplier [STEMMA QT/Qwiic]: ID 1085: Adafruit Industries, Unique & fun DIY electronics and kits (https://www.adafruit.com/product/1085)

16: 17 Analog Sensor Board - Smart Citizen Docs (https://docs.smartcitizen.me/hardware/boards/analog-sensor-board/)

18 19 ADS111x Ultra-Small, Low-Power, I2 C-Compatible, 860SPS, 16-Bit ADCs with Internal Reference, Oscillator, and Programmable Comparator datasheet (Rev.
E) (https://www.ti.com/lit/ds/symlink/ads1115.pdf)

20 21 Fermion: MCP3424 18-Bit ADC-4 Channel with Programmable Gain Ampli-er - DFRobot (https://www.dfrobot.com/product-1182.html)

22 23 24 24 Bit 8 Channel ADS1256 ADC Data Acquisition Board Module AD Collecting Data Acquisition Card High Precision: Amazon.com: Industrial & Scientic (https://www.amazon.com/Channel-ADS1256-Acquisition-Collecting-Precision/dp/B0DBSWRQZS)

25 TDS OX-B431 Apr 16.pmd (https://www.isweek.com/Uploads/20161216/5853470876f70.pdf)

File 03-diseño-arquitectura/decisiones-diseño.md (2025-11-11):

# Decisiones de diseño registradas

1. **Sincronización en plataforma única:** Se decidió integrar todos los sensores (electroquímicos, ópticos y meteorológicos) en la misma plataforma para garantizar análisis en tiempo casi real.
2. **Energía autónoma:** El uso de panel solar + banco de baterías responde a la necesidad explícita de operación autónoma indicada en el brochure.
3. **Comunicaciones GSM/4G + microSD:** La combinación permite transmisión remota y respaldo local, tal como se describe en la configuración del sistema.
4. **Selección Plantower PMS5003ST:** Se escogió por su límite de detección de 1 µg/m³ y precisión ±1 µg/m³ para PM₁.₀, PM₂.₅ y PM₁₀.
5. **Selección Alphasense serie B4/B43F:** La decisión garantiza límites de detección de 1 ppb (1 ppm para CO) con precisión ±1 ppbv (±1 ppmv para CO) y estabilidad declarada.
6. **Integración RS485 (Modbus):** La estación digital multiparámetro RS485 proporciona las variables meteorológicas requeridas y facilita la conexión con el datalogger.
7. **Muestreo pasivo complementario:** Se incorpora un sistema compatible con Resolución Exenta N° 1449 (MMA, 2023) para material particulado sedimentable.

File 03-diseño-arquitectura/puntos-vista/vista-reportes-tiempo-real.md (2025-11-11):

# Vista de reportes en tiempo casi real
- El flujo de datos considera transmisión GSM/4G complementada con microSD para redundancia.
- Las aplicaciones objetivo (monitoreo ciudadano, validación de sensores, correlación con referencia y evaluación de impacto) se alimentan directamente de este flujo.
- La arquitectura autónoma (panel solar + baterías) permite mantener los reportes aun fuera de red eléctrica.

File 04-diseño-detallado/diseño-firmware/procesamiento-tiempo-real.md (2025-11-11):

# Procesamiento en tiempo casi real
- Los datos se procesan de manera continua para habilitar reportes inmediatos vía GSM/4G.
- El almacenamiento en microSD actúa como respaldo cuando no hay conectividad sin alterar la periodicidad.

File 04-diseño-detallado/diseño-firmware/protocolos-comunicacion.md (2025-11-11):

# Protocolos de comunicación
- RS485 (Modbus) para la estación meteorológica digital ComWinTop.
- GSM/4G para telemetría principal.
- MicroSD para almacenamiento local (no requiere protocolo externo, actúa como respaldo).

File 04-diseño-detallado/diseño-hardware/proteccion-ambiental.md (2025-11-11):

# Protección ambiental
El brochure técnico no describe características específicas de protección (carcasas o blindajes). Se requiere complementar esta sección cuando se disponga de la información del diseño definitivo.

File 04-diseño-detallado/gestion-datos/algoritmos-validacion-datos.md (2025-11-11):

# Algoritmos de validación de datos
No se describieron algoritmos específicos en el brochure técnico. Se necesita información adicional para documentar los criterios (banderas automáticas, detección de eventos, etc.).

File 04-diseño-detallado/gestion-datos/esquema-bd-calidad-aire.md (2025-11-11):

# Esquema de base de datos
No se entregó información del esquema en el brochure. Debe completarse cuando se definan las tablas (contaminantes, meteorología, QA/QC, etc.).

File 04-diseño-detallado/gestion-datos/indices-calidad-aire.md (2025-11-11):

# Índices de calidad del aire
El brochure no especifica índices calculados (por ejemplo, ICA). Queda pendiente documentar fórmulas una vez definidas.

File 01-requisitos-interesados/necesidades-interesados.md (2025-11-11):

# Necesidades de los interesados
Las siguientes necesidades se derivan de la descripción del brochure técnico.

| Interesado | Necesidad explícita | Referencia en brochure |
| --- | --- | --- |
| Operadores municipales | Monitoreo continuo de calidad del aire y condiciones meteorológicas en una sola plataforma. | Chips “Monitoreo continuo” y descripción general. |
| Equipo de campo | Sistema autónomo mediante panel solar y banco de baterías para operar sin red eléctrica. | Configuración del sistema. |
| Equipo de comunicaciones | Transmisión de datos vía GSM/4G con respaldo local en microSD. | Configuración del sistema. |
| Equipo de mantenimiento | Acceso rápido a módulos para reemplazos y calibración previa a la operación. | Configuración del sistema y estado actual. |
| Científicos/analistas | Datos en tiempo casi real para correlacionar contaminantes y meteorología con sensores sincronizados. | Descripción general. |
| Reguladores/QA-QC | Sensores con especificaciones validadas y calibración antes de su uso. | Descripción general. |
| Programas comunitarios | Estación autónoma instalada en torres de 2–5 m con exposición 360° y altura de muestreo a 1,5 m. | Configuración del sistema. |

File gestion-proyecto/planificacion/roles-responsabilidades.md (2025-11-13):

# Roles y responsabilidades
Basado en el brochure técnico y las definiciones entregadas por el equipo.

| Rol | Responsable | Responsabilidades principales |
| --- | --- | --- |
| Director/a del proyecto | Zoe Fleming | Define lineamientos estratégicos, asegura recursos y alinea el proyecto con objetivos institucionales. |
| Coordinador del equipo | Luis Gómez | Coordina disciplinas, consolida reportes de avance y mantiene comunicación con interesados clave. |
| Coordinador de firmware y comunicaciones | Alejandro Rebolledo | Coordina electrónica. Lidera programación del firmware, integra sensores con la plataforma y mantiene las telecomunicaciones GSM/4G y RS485/Modbus.|
| Coordinación de terreno | Pablo Ortiz | Gestiona despliegues de torres, logística de instalaciones y soporte de campo durante pruebas y funcionamiento;  coordina muestreo pasivo. |
| Coordinación de mediciones y datos | Catalina Azola | Define rutinas de adquisición, asegura calidad del muestreo. Administra la carga de datos, verifica consistencia en `datos/datos-muestra` y coordina análisis. |
| Encargado de documentación regulatoria, QA/QC de datos y bases de datos | Christopher Silva | Mantiene documentación regulatoria, valida la calidad de los datos, gestiona respaldos y define controles sobre las bases almacenadas en `datos/`. |
| Diseñador de hardware y componentes | Rodrigo Ortega | Diseña el soporte físico, integra panel solar + banco de baterías y selecciona componentes mecánicos y de protección. |
| Diseñador electrónico | Sebastián Adonay | Desarrolla el diseño electrónico de adquisición, alimentación y acondicionamiento para sensores electroquímicos, ópticos y meteorológicos. |

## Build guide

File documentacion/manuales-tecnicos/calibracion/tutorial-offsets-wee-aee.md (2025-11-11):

# 📋 Guía Práctica: Medición de WEe y AEe – Offsets Electrónicos

## 🎯 Objetivo
Medir los voltajes de offset electrónico (WEe y AEe) de una placa AFE o ISB de Alphasense **sin sensor conectado**, utilizando un multímetro común.

---

## ⚠️ Precauciones de seguridad
- **Desconectar la alimentación** antes de conectar o desconectar componentes.
- Utilizar **protección ESD** (pulsera antiestática) cuando sea posible.
- **Verificar la polaridad** de las puntas del multímetro antes de medir.
- **No tocar** componentes expuestos con las manos durante la medición.

---

## 🛠️ Equipamiento requerido
| Ítem | Especificaciones | Notas |
| --- | --- | --- |
| **Multímetro digital** | Rango VDC: 0–2 V o 0–20 V; resolución ≤1 mV; precisión ±0,5 % | Mínimo 3,5 dígitos |
| **Fuente de alimentación** | 3,3 V o 5 V DC | Según la placa |
| **Cables de prueba** | Puntas cocodrilo o pinzas | Para conexión segura |
| **Placa AFE/ISB** | Alphasense o compatible | Sin sensor conectado |

---

## 📝 Procedimiento paso a paso

### Paso 1: Preparación del sistema
```
1. ▢ Asegurar que la placa esté APAGADA.
2. ▢ Desconectar completamente el sensor de gas.
3. ▢ Verificar que no hay cortocircuitos visibles.
4. ▢ Conectar la alimentación a la placa.
```

### Paso 2: Configuración del multímetro
```
1. ▢ Encender el multímetro.
2. ▢ Seleccionar modo "VDC" (voltaje DC).
3. ▢ Seleccionar rango "2 V DC" (preferido) o "20 V DC".
4. ▢ Verificar que muestre "0.000" en cortocircuito.
```

### Paso 3: Identificación de puntos de medición
```
┌─────────────────────┐
│    PLACA AFE/ISB    │
├─────────────────────┤
│ WE_OUT ────────○    │  ← Punta ROJA (+)
│                 │   │
│ AE_OUT ────────○    │  ← Punta ROJA (+)
│                 │   │
│ GND ───────────○    │  ← Punta NEGRA (−)
└─────────────────────┘
```

### Paso 4: Medición de WEe
```
1. ▢ Conectar punta NEGRA (−) a GND de la placa.
2. ▢ Conectar punta ROJA (+) a WE_OUT.
3. ▢ Esperar 10–15 segundos para estabilización.
4. ▢ Anotar valor estable: __________ mV ← WEe.
```

### Paso 5: Medición de AEe
```
1. ▢ Mantener punta NEGRA (−) en GND.
2. ▢ Mover punta ROJA (+) a AE_OUT.
3. ▢ Esperar 10–15 segundos para estabilización.
4. ▢ Anotar valor estable: __________ mV ← AEe.
```

---

## 📊 Valores esperados y diagnóstico

### Rango normal
| Parámetro | Valor esperado | Observaciones |
| --- | --- | --- |
| **WEe** | 200–300 mV | Valor típico Alphasense |
| **AEe** | 200–300 mV | Valor típico Alphasense |
| **Diferencia WEe−AEe** | ±50 mV | Normalmente similares |

### Diagnóstico de problemas
| Escenario | Valores medidos | Diagnóstico | Acción |
| --- | --- | --- | --- |
| ✅ Normal | WEe = 247 mV, AEe = 253 mV | Placa OK | Seguir con uso |
| ❌ Cero | WEe ≈ 2 mV, AEe ≈ 1 mV | Sin alimentación o medición incorrecta | Revisar fuente |
| ❌ Muy alto | WEe ≈ 850 mV, AEe ≈ 810 mV | Daño en componentes | Revisar placa |
| ❌ Inestable | Fluctúa ±20 mV | Ruido o mala conexión | Verificar tierra |
| ❌ Negativos | WEe = −245 mV, AEe = −251 mV | Polaridad invertida | Revisar diseño |

---

## 🧮 Ejemplo de registro
**Fecha:** ____________________  
**Operador:** ____________________  
**Placa:** AFE-12345  
**Multímetro:** Fluke 17B+

| Parámetro | Valor medido | Estado |
| --- | --- | --- |
| **WEe** | 248 mV | ✅ OK |
| **AEe** | 255 mV | ✅ OK |
| **Diferencia** | 7 mV | ✅ OK |
| **Temperatura ambiente** | 23 °C | — |

**Observaciones:** Valores dentro del rango esperado. Placa en condiciones normales.

---

## 💾 Uso de los valores

### En código (Arduino)
```cpp
// Offsets electrónicos medidos
const float WE_ELECTRONIC_OFFSET = 248.0;  // mV
const float AE_ELECTRONIC_OFFSET = 255.0;  // mV

float readCorrectedWE() {
    float raw_we = readADC(WE_CHANNEL);
    return raw_we - WE_ELECTRONIC_OFFSET;
}
```

### En configuración
```json
{
    "board_calibration": {
        "we_electronic_offset": 248.0,
        "ae_electronic_offset": 255.0,
        "measurement_date": "2024-01-15",
        "temperature": 23.0
    }
}
```

---

## 🔄 Verificación periódica
| Frecuencia | Acción | Criterio |
| --- | --- | --- |
| Inicial | Medición completa | 200–300 mV |
| Cada 6 meses | Verificación | Cambio < ±10 mV |
| Después de impactos | Verificación inmediata | Valores estables |

---

## ❓ Preguntas frecuentes
**¿Los offsets cambian con el tiempo?**  
Normalmente son estables, pero pueden variar con temperatura extrema o daños físicos.

**¿Qué hago si mis valores están fuera de rango?**  
Contactar al fabricante o revisar la placa por daños.

**¿Puedo ajustar estos offsets a cero?**  
No es recomendable; se compensan en software.

---

## ✅ Checklist final
- [ ] Multímetro calibrado y funcionando.
- [ ] Sensor desconectado.
- [ ] Puntas de prueba en buen estado.
- [ ] Valores anotados correctamente.
- [ ] Valores dentro de 200–300 mV.
- [ ] Documentación actualizada.

**¡Medición completada!** 🎉

---

*Documento versión 1.0 – Basado en AAN-803-05 de Alphasense.*  
*Última actualización: enero 2024.*

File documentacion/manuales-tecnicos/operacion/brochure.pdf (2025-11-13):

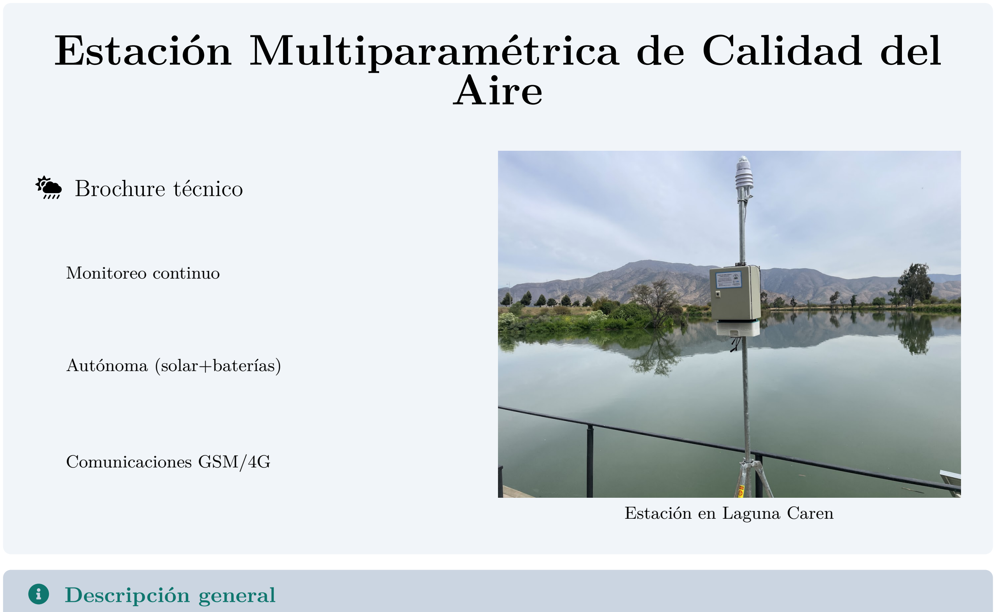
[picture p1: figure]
Aire; Ê Brochure técnico; Monitoreo continuo; Autónoma (solar+baterías); Comunicaciones GSM/4G; Estación en Laguna Caren; á Descripción general

# Estación Multiparamétrica de Calidad del

La estación integra sensores electroquímicos, ópticos y meteorológicos en una estructura vertical compacta. El sistema recolecta, almacena y transmite datos en tiempo casi real, permitiendo el análisis conjunto de calidad del aire y condiciones meteo.

Estado actual: construcción y pruebas de campo; todos los sensores cuentan con especificaciones validadas y se calibran previamente a su operación.

Ñ Configuración del sistema

Soporte: torre 2–5 m, exposición 360°.

Energía: panel solar + banco de baterías.

Comms: GSM/4G y microSD local.

Integración: plataforma única, sensores sin-

cronizados.

Altura de medición: 1,5 m s.n.s.

Mantenimiento: módulos accesibles, reemplazo rápido.

ì Material particulado

Parámetro | Sensor | Límite det. Precisión | Tecnología
PM1.0/PM2.5/PM10 | Plantower PMS5003ST 1 µg/m³ | ±1 µg/m³ | Óptico láser

¡ Gases criterio — Alphasense serie B4/B43F

Sensores amperométricos de alta selectividad y estabilidad.

Gas | Modelo | Límite det. Precisión | Comentario
O3 | OX-B431 | 1 ppb | ±1 ppbv | Cartucho combinado O3/NO2 (anillo do-
| | | | rado).
NO2 | NO2-B43F 1 ppb | ±1 ppbv | Filtro químico que suprime interferencia
| | | | de O3.
CO | CO-B4 | 1 ppm | ±1 ppmv Adecuado para eventos altos; baja deri-
| | | | va.
NO | NO-B4 | 1 ppb | ±1 ppbv | Respuesta rápida, buena linealidad en
| | | | bajas ppb.

* Nota: En contexto urbano típico, CO y SO2 pueden estar bajo el límite de detección; estos canales se orientan a eventos significativos.

o Gases adicionales

Gas | Sensor | Tecnología | Resolución
CO2 | Winsen MH-Z19B Infrarrojo NDIR 1 ppm
SO2 | Por definir | Electroquímico | 100 ppb (objetivo)
COV totales | Por definir | PID o MOS | 1 ppm (objetivo)
- Sensores meteorológicos

Estación digital multiparámetro RS485 (Modbus).

Temperatura, humedad relativa, presión, velocidad y dirección del viento.

Salida digital estable y fácil integración con el datalogger.

` Equipos de muestreo pasivo

Colectores de material particulado sedimentable (fabricación local).

Conforme a Resolución Exenta N° 1449 (MMA, 2023).

Principio: deposición gravitacional para fracción gruesa.

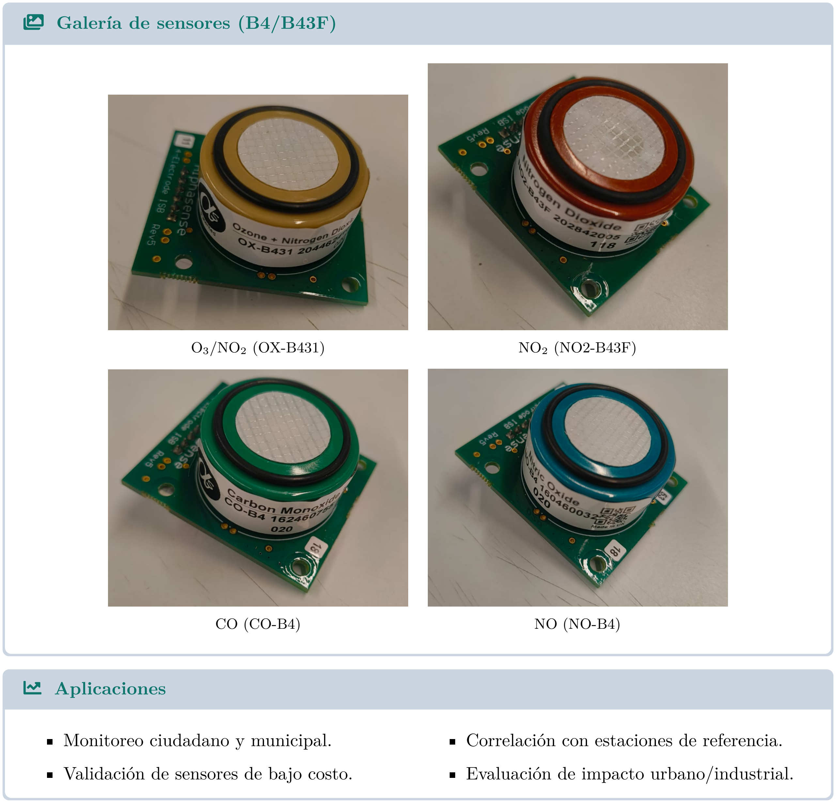
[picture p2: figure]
Û Galería de sensores (B4/B43F);  Aplicaciones; Monitoreo ciudadano y municipal.; Validación de sensores de bajo costo.; Correlación con estaciones de referencia.; Evaluación de impacto urbano/industrial.

colorline Proyecto en desarrollo: Estación Multiparamétrica de Monitoreo Ambiental | Contacto: luis.gomez@udd.cl

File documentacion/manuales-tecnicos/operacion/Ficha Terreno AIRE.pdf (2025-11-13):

# FICHA DE TERRENO

## Verificación de Sensores Meteorológicos y Calidad del Aire

INFORMACIÓN GENERAL

Campo | | Valor
Fecha de Inspección | __/__/__
Hora de Inicio | __:__
Hora de Término | __:__
Técnico Responsable | _________________________
Código/ID Estación | _________________________
Ubicación | _________________________
Coordenadas GPS | Lat: _________ Long: _________

Tipo de Calibración: ☐ Calibración corta en terreno (1-2 horas) ☐ Calibración completa con cambio equipos ☐ Solo verificación y mantenimiento

Condiciones Meteorológicas Durante Inspección:
Temperatura: ____°C
Humedad: ____%
Viento : ☐ Calmo ☐ Ligero ☐ Moderado ☐ Fuerte Precipitación : ☐ Sin lluvia ☐ Llovizna ☐ Lluvia ligera ☐ Lluvia intensa Nubosidad : ☐ despejado ☐ parcial ☐ cubierto ☐ neblina

### 1. INSPECCIÓN VISUAL GENERAL

Elemento | Bueno Regular Malo | Observaciones
Estado estructura/torre | ☐ | ☐ | ☐
Carcasas y protecciones | ☐ | ☐ | ☐
Cables y conexiones | ☐ | ☐ | ☐
Ausencia de corrosión | ☐ | ☐ | ☐
Limpieza general | ☐ | ☐ | ☐

Elemento | Bueno Regular Malo | Observaciones
Sin obstrucciones | ☐ | ☐ | ☐

Obstrucciones encontradas:
☐ Nidos de aves ☐ Vegetación ☐ Acumulación suciedad ☐ Otros: _______________

### 2. SENSORES DE CALIDAD DEL AIRE

### 2.1 MATERIAL PARTICULADO FILTRO

Sensor Marca/Modelo Instalado Funcionand o

Bomba
OK

Filtro
OK

Caudal
| | | | | OK | T° Operación
PM2.5 | ☐ | ☐ | ☐ | ☐ | ☐ | ____°C

Verificación de Caudal PM2.5:
Caudal nominal: 10 L/min
Caudal medido: _____ L/min Estado: ☐ OK ☐ Requiere ajuste

### 2.2 GASES CONTAMINANTES

Contaminant
e

Marca/Mo
delo

Instalad
o

Funcionand
o

Temp.
Operación

Línea
Muestreo OK

Serie de
Tiempo
O₃ (ozono) | ☐ | ☐ | ____°C | ☐ | ☐ Sí ☐ No
CO | ☐ | ☐ | ____°C | ☐ | ☐ Sí ☐ No
NO₂ | ☐ | ☐ | ____°C | ☐ | ☐ Sí ☐ No
NO | ☐ | ☐ | ____°C | ☐ | ☐ Sí ☐ No
SO₂ | ☐ | ☐ | ____°C | ☐ | ☐ Sí ☐ No
CO Total | ☐ | ☐ | ____°C | ☐ | ☐ Sí ☐ No
CO₂ | ☐ | ☐ | ____°C | ☐ | ☐ Sí ☐ No
Sensores de Bajo Costo (Plantower/Alfasens):
☐ Requieren calibración con sensor de referencia
☐ Última calibración laboratorio: __/__/__
☐ Próxima calibración laboratorio programada: __/__/__

### 3. SENSORES METEOROLÓGICOS

### 3.1 VIENTO

Parámetro | Frecuencia Unidad | Funcionando Valor Actual Observaciones
Dirección | 1 hora | ° (ángulo) | ☐ | ____°
Velocidad | 1 hora | m/s | ☐ | ____m/s

Verificación Mecánica:

Componente | Funciona Bien | Requiere Mantenimiento | No Funciona
Anemómetro
(rotación) | | ☐ | | ☐ | ☐
Veleta (movimiento) | ☐ | ☐ | ☐
Rodamientos | | ☐ | | ☐ | ☐

### 3.2 TEMPERATURA AIRE

Parámetro | Frecuencia Unidad Funcionando Valor Actual | Sensor Referencia
Temperatura | 1 hora | °C | ☐ | ____°C | ____°C
Estado: ☐ Aceptable ☐ Requiere calibración

### 3.3 PRECIPITACIÓN

Parámetro | Prueba | Unidad Funcionando Observaciones
Precipitación | 20 | mm | ☐
Verificación Física:
Elemento | OK | Requiere Atención | Observaciones
Pluviómetro
nivelado | ☐ | ☐
Embudo limpio | ☐ | ☐
Mecanismo
basculante | ☐ | ☐
Sin obstrucciones | ☐ | ☐

### 3.4 RADIACIÓN

Parámetro | Frecuencia | Unidad | Funcionando Valor Actual Observaciones
Radiación Total | 1 hora | W/m² | ☐ | ____W/m²
Radiación UV | 1 hora | W/m² o UV
| | index | ☐ | ____

### 3.5 FOTOGRAFÍA

Parámetro | Frecuencia | Funcionando | Observaciones
Foto horizonte | 3 horas | ☐

### 3.6 CAPTADOR PASIVO

Parámetro | Frecuencia | Estado | Próximo Envío
Laboratorio
Material Particulado
Sedimentado | 1 mes | ☐ Instalado ☐ Para retirar | __/__/__

### 4. CALIBRACIÓN EN TERRENO

### 4.1 CALIBRACIÓN CORTA (1-2 HORAS)

Sensores PM (con sensor de referencia calibrado):

Sensor | Lectura Sensor
| Campo | Lectura Sensor
| | Referencia | Factor
| | | Corrección | Aplicado
PM2.5 | ____μg/m³ | ____μg/m³ | ____ | ☐
Sensores Gases (Plantower/Alfasens vs Referencia):
Contaminante | Lectura
Campo | Lectura Referencia Factor Corrección | Aplicado
O₃ | ____ppb | ____ppb | ____ | ☐
CO | ____ppm | ____ppm | ____ | ☐
NO₂ | ____ppb | ____ppb | ____ | ☐
NO | ____ppb | ____ppb | ____ | ☐
SO₂ | ____ppb | ____ppb | ____ | ☐
CO₂ | ____ppm | ____ppm | ____ | ☐

### 4.2 PROGRAMA CALIBRACIÓN LABORATORIO

Senso r | Última Calibración
| Lab | Próxima
Calibración | Estado
PM2.5 __/__/__ | __/__/__ | ☐ Vigente ☐ Vencida
O₃ | __/__/__ | __/__/__ | ☐ Vigente ☐ Vencida
CO | __/__/__ | __/__/__ | ☐ Vigente ☐ Vencida
NO₂ | __/__/__ | __/__/__ | ☐ Vigente ☐ Vencida
NO | __/__/__ | __/__/__ | ☐ Vigente ☐ Vencida
SO₂ | __/__/__ | __/__/__ | ☐ Vigente ☐ Vencida
CO₂ | __/__/__ | __/__/__ | ☐ Vigente ☐ Vencida
Sensores programados para retiro:

### 5. SISTEMA ELÉCTRICO Y COMUNICACIONES

Componente | Medición/Estado | OK | Requiere
| | | Atención | Observaciones

Voltaje
Alimentación | _____ V | ☐ | ☐
Baterías Respaldo | _____ V | ☐ | ☐
Panel Solar | _____ V | ☐ | ☐
Conectividad | ☐ GSM ☐ WiFi ☐ sin | ☐ | ☐

Transmisión de Datos: ☐ Datos transmitiendo correctamente ☐ Datos con retrasos ☐ Sin transmisión de datos ☐ Transmisión intermitente

### 6. VERIFICACIÓN DE SERIES DE TIEMPO

Sensor | Serie
Continua

Valores
Coherentes

Fecha Última
Lectura

Observacion
es
PM2.5 | ☐ | ☐ | __/__/__
O₃ | ☐ | ☐ | __/__/__
CO | ☐ | ☐ | __/__/__
NO₂ | ☐ | ☐ | __/__/__
NO | ☐ | ☐ | __/__/__
SO₂ | ☐ | ☐ | __/__/__
CO Total | ☐ | ☐ | __/__/__
CO₂ | ☐ | ☐ | __/__/__
Temperatura | ☐ | ☐ | __/__/__
Viento
(Dir/Vel) | ☐ | ☐ | __/__/__
Precipitación | ☐ | ☐ | __/__/__
Radiación | ☐ | ☐ | __/__/__

### 7. MANTENIMIENTO REALIZADO

Actividad | Realizado | N/A | Detalles
Limpieza sensores | ☐ | ☐
Limpieza líneas muestreo | ☐ | ☐
Reemplazo filtros PM | ☐ | ☐
Lubricación anemómetro | ☐ | ☐
Calibración corta gases | ☐ | ☐
Calibración corta PM | ☐ | ☐
Retiro sensores para lab | ☐ | ☐
Instalación sensores
calibrados | ☐ | ☐
Componentes Retirados para Laboratorio:

Componentes Instalados desde Laboratorio:

### 8. EVALUACIÓN GENERAL

Sistema | Excelente
(4)

Bueno
(3)

Regular
(2) Malo (1) Puntaje
Sensores Calidad Aire ☐ | ☐ | ☐ | ☐ | ___/4

Sistema | Excelente
(4)
| | Bueno
(3)
| | | Regular
(2) Malo (1) Puntaje

Sensores
Meteorológicos | ☐ | ☐ | ☐ | ☐ | ___/4
Calibración Estado | ☐ | ☐ | ☐ | ☐ | ___/4
Sistema Eléctrico | ☐ | ☐ | ☐ | ☐ | ___/4
Series de Tiempo | ☐ | ☐ | ☐ | ☐ | ___/4
PUNTAJE TOTAL: ___/20

### 9. OBSERVACIONES Y RECOMENDACIONES

Problemas Críticos Identificados:

Acciones Correctivas Requeridas:

Acció
n
Prioridad | Fecha Límite

Responsabl
e
☐ Alta ☐ Media ☐
Baja
☐ Alta ☐ Media ☐
Baja
☐ Alta ☐ Media ☐
Baja
Sensores que Requieren Calibración Laboratorio:

Próxima Calibración en Terreno: __/__/__ Próxima Inspección Completa: __/__/__

FIRMAS
Técnico Responsable: _________________________ Fecha: __/__/__ Supervisor: _________________________ Fecha: __/__/__

Estado Final de la Estación:
☐ Operativa - Calibración vigente ☐ Operativa - Requiere calibración próxima

☐ Operativa con restricciones
☐ Fuera de servicio ☐ Sensores retirados para calibración laboratorio

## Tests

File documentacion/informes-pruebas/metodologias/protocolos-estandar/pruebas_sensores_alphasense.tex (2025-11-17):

\documentclass[12pt]{article}
\usepackage[utf8]{inputenc}
\usepackage[spanish]{babel}
\usepackage{amsmath, amssymb}
\usepackage{siunitx} % <-- Para unidades SI
\usepackage{geometry}
\usepackage{hyperref}
\usepackage{graphicx}
\usepackage{enumitem}
\usepackage{tcolorbox}
\usepackage{pifont}

\geometry{margin=2.5cm}

\title{Recomendaciones y Pruebas Eléctricas para Sensores Alphasense}
\author{}
\date{\today}

\begin{document}
	
	\maketitle
	
	\section*{1. Objetivo}
	Establecer una metodología de prueba para verificar condiciones eléctricas, consumo y niveles de ruido en sensores de gases electroquímicos Alphasense. Se busca identificar la calidad de alimentación y tierra, así como caracterizar el comportamiento eléctrico de cada sensor de forma individual y repetir pruebas para todos los sensores conectados en serie.
	
	\section*{2. Equipamiento Recomendado}
	\begin{itemize}[label=\textbullet]
		\item Multímetro de precisión (resolución de al menos \SI{1}{\milli\volt} / \SI{1}{\micro\ampere})
		\item Osciloscopio (\(\geq \SI{20}{\mega\hertz}\) de ancho de banda, con opción AC/DC y modo diferencial)
		\item Sonda de corriente (ej. tipo Hall o shunt de bajo valor con amplificador)
		\item Fuente regulada de laboratorio con bajo ruido (usar Nordic PPK para pruebas individuales)
		\item Cables blindados y clips Kelvin (para medidas diferenciales)
	\end{itemize}
	
	\section*{3. Mediciones a Realizar}
	
	\subsection*{3.1. Medición de Voltaje de Alimentación (V\textsubscript{IN})}
	\begin{itemize}
		\item Medir tensión DC entre pin VCC y GND del conector ISB.
		\item Repetir la medición en la entrada y salida del regulador LDO.
		\item Registrar valores típicos y desviaciones bajo carga.
		\item Registrar valores de ruido en los pines de GND.
	\end{itemize}
	
	\subsection*{3.2. Medición de Corriente de Consumo}
	\begin{itemize}
		\item Usar multímetro en serie.
		\item Alternativamente, utilizar sonda de corriente si se desea no invadir la línea.
	\end{itemize}
	
	\subsection*{3.3. Medición de Ruido en la Alimentación}
	\begin{itemize}
		\item Conectar el osciloscopio en modo AC entre VCC y GND del sensor.
		\item Evaluar rizado de alta frecuencia (\(> \SI{10}{\kilo\hertz}\)), spikes o modulación.
		\item Repetir en la salida del LDO y entrada del sensor.
	\end{itemize}
	
	\subsection*{3.4. Medición de Ruido en la Línea de Tierra (GND)}
	\begin{itemize}
		\item Configurar osciloscopio en modo diferencial (revisar manual del equipo).
		\item Medir entre GND del sensor y GND central del sistema (fuente o plano principal).
		\item Identificar diferencias de potencial o corrientes parásitas.
	\end{itemize}

\begin{tcolorbox}[colback=gray!10,colframe=black,title={Medición sin Sonda Diferencial (Método con dos canales)}]
	
	\textbf{Si NO tienes sonda diferencial, realiza lo siguiente:}
	
	\begin{itemize}
		\item \textbf{Canal 1 (CH1):}  
		Conectar solo la punta de la sonda en \textbf{GND del sensor}.  
		\textbf{No usar el clip de tierra} (muy importante).
		
		\item \textbf{Canal 2 (CH2):}  
		Conectar solo la punta de la sonda en \textbf{GND de la fuente}.  
		Nuevamente, \textbf{no usar el clip de tierra}.
	\end{itemize}
	
	\textbf{Ajustes en el osciloscopio:}
	
	\begin{itemize}
		\item Activar función \texttt{Math → CH1 – CH2}
		\item Seleccionar \textbf{acoplamiento AC}
		\item Usar sensibilidad de \textbf{1–2 mV/div}
	\end{itemize}
	
	Con esto se genera un \textbf{canal virtual diferencial} que permite medir la diferencia real entre las tierras sin riesgo de cortocircuito.
	
	\begin{center}
		\textcolor{yellow}{\ding{115}}  \textcolor{red}{\large Advertencia Importante}
	\end{center}
	
	\textbf{No utilizar los clips de tierra de las sondas.}  
	Hacerlo puede generar un \textbf{cortocircuito} o crear un \textbf{bucle de masa grande}, introduciendo ruido o dañando el equipo.
	
\end{tcolorbox}
	
	\section*{4. Consideraciones}
	\begin{itemize}
		\item Asegurar conexiones de baja impedancia y minimizar bucles de masa.
		\item Utilizar cables cortos y bien acoplados.
		\item Evitar puntos de masa flotantes entre sensor y regulador.
		\item Repetir pruebas con carga activa (sensor funcionando) y en reposo.
	\end{itemize}
	
	\section*{5. Registro de Datos}
	Crear una tabla por sensor con los siguientes campos:
	\begin{itemize}
		\item ID del sensor
		\item Tensión de entrada (antes del LDO)
		\item Tensión de salida (en el sensor)
		\item Corriente media
		\item Rizado pico a pico observado
		\item Diferencia de potencial GND–GND (sensor–fuente)
		
		\begin{figure}
			\centering
			
			\caption{Revisar continuidad de GND y ruido en pines 2, 4 y 6}
			\label{fig:placeholder}
		\end{figure}
	\end{itemize}
	
\end{document}

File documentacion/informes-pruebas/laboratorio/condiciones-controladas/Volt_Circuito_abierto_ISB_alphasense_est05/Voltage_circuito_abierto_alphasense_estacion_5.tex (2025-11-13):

%-------------------------------------------------------
%   REPORTE TÉCNICO – FORMATO MODERNO (PDFLATEX)
%-------------------------------------------------------
\documentclass[11pt]{article}

%-------------------------------------------------------
%   PAQUETES DE DISEÑO COMPATIBLES
%-------------------------------------------------------
\usepackage[a4paper,margin=2.2cm]{geometry}
\usepackage[T1]{fontenc}
\usepackage[utf8]{inputenc}
\usepackage{lmodern} % Fuente moderna compatible
\usepackage{titlesec}
\usepackage{microtype}
\usepackage{setspace}
\usepackage{paracol}
\usepackage{graphicx}
\usepackage{booktabs}
\usepackage{tcolorbox}
\usepackage{hyperref}
\usepackage{multicol}
\usepackage{siunitx}
\usepackage{xcolor}

\usepackage{subcaption}
\usepackage{caption}

%-------------------------------------------------------
%   COLORES PERSONALIZADOS
%-------------------------------------------------------
\definecolor{uddblue}{HTML}{003366}
\definecolor{graytext}{HTML}{3A3A3A}

%-------------------------------------------------------
%   ESTILO DE TÍTULOS
%-------------------------------------------------------
\titleformat{\section}{\Large\bfseries\color{uddblue}}{}{0em}{}[\titlerule]
\titleformat{\subsection}{\large\bfseries\color{uddblue}}{}{0em}{}
\titleformat{\subsubsection}{\normalsize\bfseries\color{uddblue}}{}{0em}{}

% Hipervínculos
\hypersetup{
	colorlinks=true,
	linkcolor=uddblue,
	urlcolor=uddblue,
}

% Cuadros modernos
\tcbset{
	sharp corners,
	colback=white,
	colframe=uddblue,
	left=8pt,
	right=8pt,
	top=6pt,
	bottom=6pt,
}

%-------------------------------------------------------
%   DOCUMENTO
%-------------------------------------------------------
\begin{document}
	
	%-------------------------------------------------------
	% PORTADA
	%-------------------------------------------------------
	\begin{center}
		{\huge \bfseries Medición de Offset Electrónico}\\[4pt]
		{\Large \bfseries (Open Circuit Voltage – OCV)}\\[8pt]
		\rule{0.9\textwidth}{1pt}\\[10pt]
	\end{center}
\begin{figure}[h]
	\centering
	
	\caption{Placa Alphasense ISB}
	\label{fig:img1555}
\end{figure}

	\begin{tcolorbox}
		\textbf{Responsable:} Luis Gómez (\href{mailto:luis.gomez@udd.cl}{luis.gomez@udd.cl})\\
		\textbf{Revisores:} Alejandro Rebolledo (\href{mailto:arebolledo@udd.cl}{arebolledo@udd.cl})\\ % me agrego como revisor
		\textbf{Lugar:} Laboratorio de Electrónica C+ — UDD, Santiago\\
		\textbf{Fecha:} 11 noviembre 2025 (10:00–13:52)\\
		\textbf{Estación evaluada:} Estación 5\\
		\textbf{Proyecto:} Linea base pública para la región metropolitana
	\end{tcolorbox}
	
	%-------------------------------------------------------
	\section{Propósito del Test}
	
	El objetivo del ensayo fue cuantificar el \textbf{offset electrónico intrínseco} generado por la placa
	Alphasense ISB cuando opera \textbf{sin sensor conectado} (condición de circuito abierto).  
	Este voltaje corresponde exclusivamente a la acción de la electrónica interna del módulo 
	(amplificadores, referencias y filtros) y constituye el valor base que debe restarse a las mediciones reales del sensor para separar:
	\begin{itemize}
		\item el offset electrónico (\textbf{WEe}, \textbf{AEe}),
		\item el offset propio del sensor (\textbf{WEo}, \textbf{AEo}).
	\end{itemize}
	
	Según la documentación técnica de Alphasense, el rango típico esperado para los canales OP1 (WE)
	y OP2 (Aux) se encuentra entre \textbf{200 y 300 mV} (ver figura).

\begin{figure}
	\centering
	
	\caption{Conexiones ISB Alphasense ISB }
	\label{fig:captura-de-pantalla-de-2025-11-12-20-29-07}
\end{figure}
	%-------------------------------------------------------
	\pagebreak
	\section{Procedimiento}
	
	\subsection*{Condiciones del ensayo (sin sensor B4)}
	\begin{itemize}
		\item Alimentación aplicada: 3.5–6.5 VDC (fuente de bajo ruido).
		\item Medición de las señales OP1 (WE) y OP2 (Aux).
		\item Evaluación exclusivamente del offset electrónico en estado de circuito abierto.
	\end{itemize}
	
	\subsection*{Equipamiento}
	\begin{itemize}
		\item Power Profile Kit II (fuente de alimentación de bajo ruido).
		\item Osciloscopio GW Instek GDS-12028.
		\item Multímetro Keysight 34461A.
	\end{itemize}

\begin{figure}[h!]
	\centering
	
	\begin{subfigure}[b]{0.32\textwidth}
		\centering
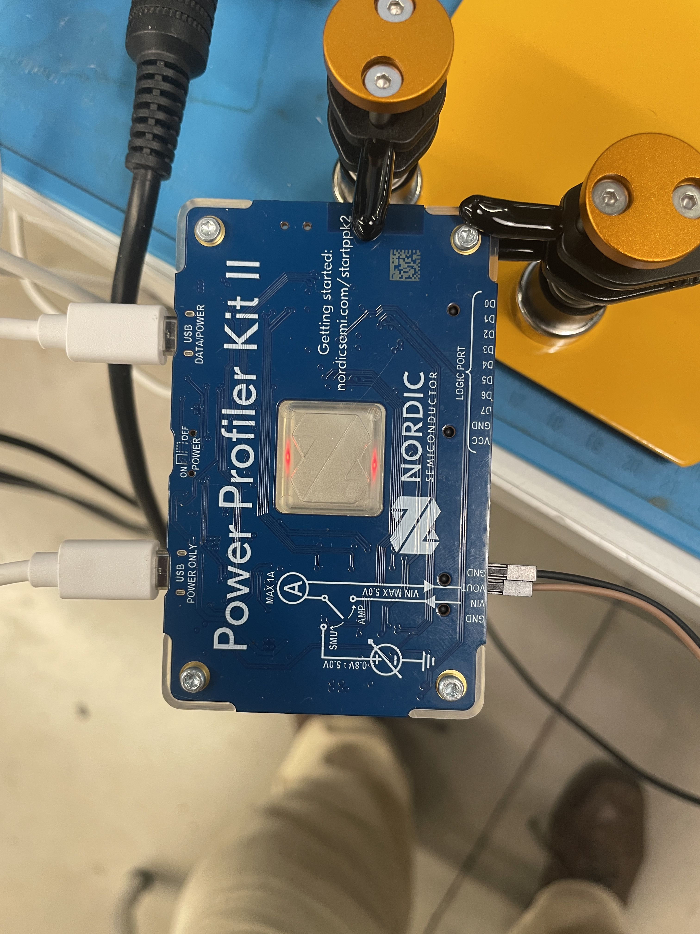
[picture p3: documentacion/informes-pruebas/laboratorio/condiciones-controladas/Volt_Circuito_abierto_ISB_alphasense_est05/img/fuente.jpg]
		
		\caption{Fuente de alimentación}
		\label{fig:fuente}
	\end{subfigure}
	\hfill
	\begin{subfigure}[b]{0.32\textwidth}
		\centering
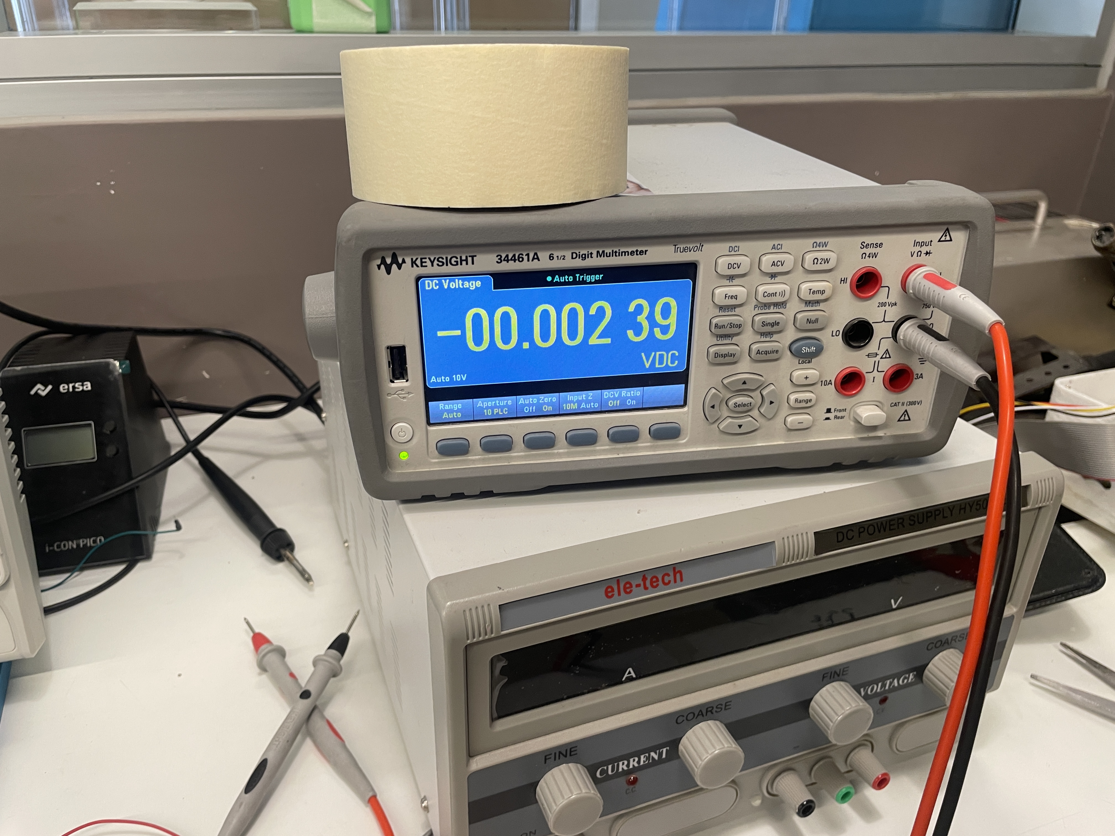
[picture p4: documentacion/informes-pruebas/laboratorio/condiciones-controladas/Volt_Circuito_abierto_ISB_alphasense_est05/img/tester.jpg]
		
		\caption{Multímetro Keysight}
		\label{fig:tester}
	\end{subfigure}
	\hfill
	\begin{subfigure}[b]{0.32\textwidth}
		\centering
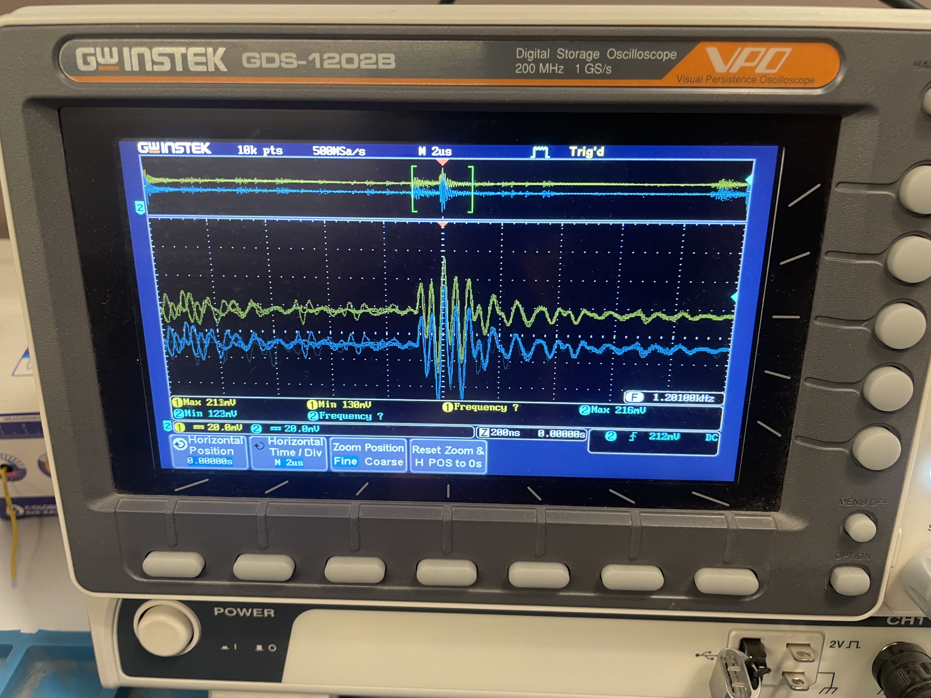
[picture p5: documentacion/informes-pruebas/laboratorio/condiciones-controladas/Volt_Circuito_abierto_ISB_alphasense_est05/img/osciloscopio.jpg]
		
		\caption{Osciloscopio GW Instek}
		\label{fig:osciloscopio}
	\end{subfigure}
	
	\caption{Equipamiento utilizado en el ensayo: fuente de bajo ruido, multímetro y osciloscopio.}
	\label{fig:equipamiento}
\end{figure}
	
	\subsection*{Procedimiento medición aplicado a cada placa ISB}
	\begin{itemize}
		\item Se extrae el sensor del socket de la placa Alphasense ISB.% aclarar que esto no es recomendable en operación normal
		\item Se conectan los cables según diagrama de la figura \ref{fig:conexiones}.%agregar figura de conexiones y agregar esquematicos
		\item Se conecta el terminal GND de la placa ISB al terminal negativo de la fuente de bajo ruido.
		\item Se conectan las tierras de los canales 1 y 2 del osciloscopio al GND de la placa.
		\item Se conectan OP1+ y OP2+ a las puntas de prueba de los canales 1 y 2 del osciloscopio, respectivamente.
		\item Se enciende la fuente de alimentación.
		\item Tras un tiempo de estabilización de 1 segundo, se conecta el terminal positivo de la fuente al pin V+ de la ISB.
		\item Se realizan las mediciones con osciloscopio y multímetro.
		\item Se apaga la fuente de alimentación y se desconecta la placa.
	\end{itemize}
	
	Este procedimiento se repitió para cinco placas ISB diferentes, identificadas como DBI 01 a DBI 05 mediante etiquetas adhesivas.

\begin{figure}[h]
	\centering
	
	\caption{Conexiones de la prueba de Offset}
	\label{fig:conexiones}
\end{figure}
	
	%-------------------------------------------------------
	\newpage
	\section{Resultados}

	\subsection{Mediciones con multímetro (TESTER)}
	
	Resultados obtenidos mediante mediciones con osciloscopio (ver tabla \ref{tab:tester}) 
	
\begin{table}[h!]
	\centering
	\caption{\textcolor{uddblue}{Valores medidos con multímetro (OP1 y OP2 en condición de circuito abierto).}}
	\label{tab:tester}
	\vspace{4pt}
	\begin{tabular}{@{}lccc@{}}
		\toprule
		\textbf{DBI} & \textbf{Gas} & \textbf{OP1+ (mV)} & \textbf{OP2+ (mV)} \\
		\midrule
		01 & CO     & 352 & 341 \\
		02 & NO$_2$ & 236 & 237 \\
		03 & NO     & 273 & 277 \\
		04 & OX     & 231 & 242 \\
		05 & SO$_2$ & 354 & 359 \\
		\bottomrule
	\end{tabular}
\end{table}

\subsection{Mediciones con osciloscopio}

Resultados obtenidos mediante mediciones con osciloscopio (ver tabla \ref{tab:osciloscopio} y´ figura \ref{fig:medicionosciloscopio}) 
	
\begin{table}[h]
	\centering
	\caption{Valores de OP1+ y OP2+ medidos con osciloscopio durante la prueba de offset electrónico.}
	\label{tab:osciloscopio}
	\begin{tabular}{lccc}
		\toprule
		\textbf{DBI} & \textbf{Gas} & \textbf{OP1+ (mV)} & \textbf{OP2+ (mV)} \\
		\midrule
		01 & CO     & 375 & 370 \\
		02 & NO$_2$ & 267 & 272 \\
		03 & NO     & 312 & 320 \\
		04 & OX     & 257 & 270 \\
		05 & SO$_2$ & 384 & 397 \\
		\bottomrule
	\end{tabular}
\end{table}
	
	\begin{figure}[h]
		\centering
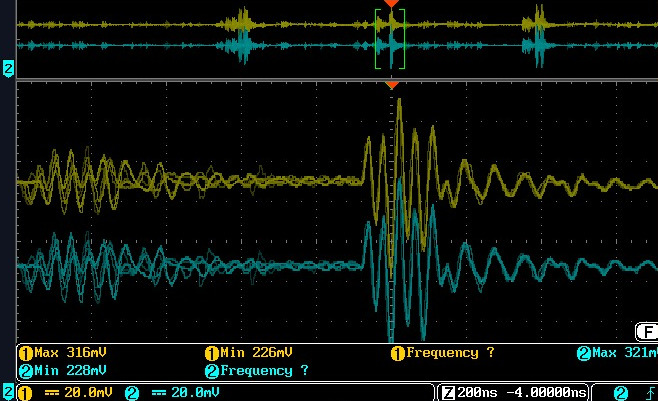
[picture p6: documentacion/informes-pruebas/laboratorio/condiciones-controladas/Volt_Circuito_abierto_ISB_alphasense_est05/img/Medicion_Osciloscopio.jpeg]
		
		\caption{salida osciloscopio de una de las pruebas para OP1+ y OP2+}
		\label{fig:medicionosciloscopio}
	\end{figure}

	%-------------------------------------------------------
\newpage
	\section{Análisis}
	
	Las mediciones obtenidas con multímetro presentan una señal estable y con menor efecto del
	ruido eléctrico, por lo que representan una mejor estimación del offset electrónico en 
	estado estacionario.
	
	Los valores correspondientes a NO$_2$, NO y OX se encuentran dentro del rango esperado 
	(200–300 mV). En contraste, las placas asociadas a CO y SO$_2$ presentan offsets superiores, 
	aunque los valores son estables y coherentes entre OP1 y OP2, indicando un comportamiento 
	normal de la electrónica del módulo.
	
	Las mediciones con osciloscopio son ligeramente mayores debido a:
	\begin{itemize}
		\item sensibilidad al ripple de la alimentación,
		\item captura de transientes breves,
		\item menor impedancia de entrada en comparación al multímetro.
	\end{itemize}
	
	%-------------------------------------------------------
	\section{Conclusiones}
	
	\begin{itemize}
		\item Las mediciones realizadas con multímetro se recomiendan para establecer los valores finales de offset electrónico \textbf{WEe} y \textbf{AEe}.
		\item No se observaron signos de saturación, fallas en amplificadores ni comportamientos anómalos en las placas ISB.
		\item Los valores caracterizados pueden ser utilizados directamente como parte del proceso de corrección electrónica previo al cálculo de concentración.
	\end{itemize}
	
	%-------------------------------------------------------
	\section{Recomendaciones}
	
	\begin{tcolorbox}
		\textbf{Para mejorar futuros ensayos, se recomienda:}
		\begin{itemize}
			\item añadir capacitores de desacople adicionales en la salida de la ISB para reducir el ruido,
			\item realizar un muestreo temporal prolongado y calcular la desviación estándar del offset,
			\item blindar cables de conexión,
			\item controlar la temperatura de la sala, ya que el offset de la electrónica presenta dependencia térmica.
			\item Medir con sensor conectado y sin gas para comparar el offset electrónico con el offset total (electrónico + sensor).%argrego recomendaciones
			\item Realizar mediciones de corriente, con y sin sensor, para evaluar el consumo en estado de circuito abierto. %argrego recomendaciones
			\item Armar pares de placa y sensor y no separarlos.
		\end{itemize}
	\end{tcolorbox}

-------------------------------------------------------
%   Bibliografía
%-------------------------------------------------------

\begin{thebibliography}{99}
	
{\small 	\bibitem{AlphasenseISB}
	Alphasense Ltd.
	\textit{4-Electrode Individual Sensor Board (ISB) User Manual}.
	Issue 7, Document 085-2217, Great Notley, Essex, UK, 2019.
	
	\bibitem{AlphasenseAAN803}
	Alphasense Ltd.
	\textit{AAN 803-05: Correcting for Background Currents in Four-Electrode Toxic Gas Sensors}.
	Application Note, 2019.
	
	\bibitem{AlphasenseB4Series}
	Alphasense Ltd.
	\textit{B4-Series Toxic Gas Sensors: Specifications}.
	Sensor Technology House, Great Notley, Essex, UK, 2019.
	
	\bibitem{Keysight34461A}
	Keysight Technologies.
	\textit{Keysight 34461A Truevolt 6½ Digit Multimeter – User’s Guide}.
	2020.
	
	\bibitem{GWInstekGDS12000}
	GW Instek.
	\textit{GDS-12000 Series Digital Oscilloscopes – User Manual}.
	2021.
	
	\bibitem{NordicPPK2}
	Nordic Semiconductor.
	\textit{Power Profiler Kit II – User Guide}.
	2023.}
	
\end{thebibliography}
	
\end{document}

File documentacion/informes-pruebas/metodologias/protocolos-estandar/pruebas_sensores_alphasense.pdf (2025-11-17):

# Recomendaciones y Pruebas Eléctricas para Sensores Alphasense

### 16 de noviembre de 2025

## 1. Objetivo

Establecer una metodología de prueba para verificar condiciones eléctricas, consumo y niveles de ruido en sensores de gases electroquímicos Alphasense. Se busca identificar la calidad de alimentación y tierra, así como caracterizar el comportamiento eléctrico de cada sensor de forma individual y repetir pruebas para todos los sensores conectados en serie.

## 2. Equipamiento Recomendado

- Multímetro de precisión (resolución de al menos 1 mV / 1 µA)
- Osciloscopio (≥ 20 MHz de ancho de banda, con opción AC/DC y modo diferencial)
- Sonda de corriente (ej. tipo Hall o shunt de bajo valor con amplificador)
- Fuente regulada de laboratorio con bajo ruido (usar Nordic PPK para pruebas individuales)
- Cables blindados y clips Kelvin (para medidas diferenciales)

## 3. Mediciones a Realizar

### 3.1. Medición de Voltaje de Alimentación (VIN)

Medir tensión DC entre pin VCC y GND del conector ISB.

Repetir la medición en la entrada y salida del regulador LDO.

Registrar valores típicos y desviaciones bajo carga.

Registrar valores de ruido en los pines de GND.

### 3.2. Medición de Corriente de Consumo

Usar multímetro en serie.

Alternativamente, utilizar sonda de corriente si se desea no invadir la línea.

### 3.3. Medición de Ruido en la Alimentación

Conectar el osciloscopio en modo AC entre VCC y GND del sensor.

Evaluar rizado de alta frecuencia (> 10 kHz), spikes o modulación.

Repetir en la salida del LDO y entrada del sensor.

### 3.4. Medición de Ruido en la Línea de Tierra (GND)

Configurar osciloscopio en modo diferencial (revisar manual del equipo).

Medir entre GND del sensor y GND central del sistema (fuente o plano principal).

Identificar diferencias de potencial o corrientes parásitas.

Medición sin Sonda Diferencial (Método con dos canales)

Si NO tienes sonda diferencial, realiza lo siguiente:

Canal 1 (CH1): Conectar solo la punta de la sonda en GND del sensor. No usar el clip de tierra (muy importante).

Canal 2 (CH2): Conectar solo la punta de la sonda en GND de la fuente. Nuevamente, no usar el clip de tierra.

Ajustes en el osciloscopio:

Activar función Math → CH1 { CH2

Seleccionar acoplamiento AC

Usar sensibilidad de 1–2 mV/div

Con esto se genera un canal virtual diferencial que permite medir la diferencia real entre las tierras sin riesgo de cortocircuito.

### ▲ Advertencia Importante

No utilizar los clips de tierra de las sondas. Hacerlo puede generar un cortocircuito o crear un bucle de masa grande, introduciendo ruido o dañando el equipo.

## 4. Consideraciones

Asegurar conexiones de baja impedancia y minimizar bucles de masa.

Utilizar cables cortos y bien acoplados.

Evitar puntos de masa flotantes entre sensor y regulador.

Repetir pruebas con carga activa (sensor funcionando) y en reposo.

## 5. Registro de Datos

Crear una tabla por sensor con los siguientes campos:

ID del sensor

Tensión de entrada (antes del LDO)

Tensión de salida (en el sensor)

Corriente media

Rizado pico a pico observado

Diferencia de potencial GND–GND (sensor–fuente)

,,

,,,,

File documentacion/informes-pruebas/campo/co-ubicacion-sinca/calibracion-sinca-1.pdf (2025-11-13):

Se realiza un análisis de las señales crudas de los sensores de bajo costo Alphasense (que miden concentraciones de NO, NO2, SO2, CO y O3) con relación a las concentraciones medidas en la estación SINCA Las Condes, separando además los datos en 3 rangos de temperaturas, definidos a partir de la temperatura registrada en la misma estación SINCA.

Se ocupan datos obtenidos entre el 11 y 28 de octubre de 2025, fechas en las que 5 de las 6 estaciones de Líneas de Base Públicas estuvieron midiendo los siguientes parámetros en el mismo lugar que los datos que se usan de referencia (SINCA).

El problema inicial es que las concentraciones obtenidas a partir de los parámetros de calibración estimados en laboratorio no coinciden con las concentraciones de la estación SINCA de referencia. Se quiere hacer una comparación entre las correlaciones observadas utilizando los parámetros de laboratorio vs. los parámetros obtenidos con la comparación con SINCA.

Para obtener los parámetros de calibración en función de los datos SINCA, se aplica la siguiente metodología:

Se utilizan los datos de temperatura de SINCA para clasificar los datos de cada estación en Baja (< 10°C), Media (entre 10 y 20°C) y Alta (> 20°C). Esto con la finalidad de obtener distintas calibraciones en función de diferentes rangos de temperatura, los rangos son elegidos en función del documento Alphasense Application Note, que muestra cómo corregir las señales de sensores Alphasense en función de la temperatura de sus registros.

○

Del total de datos disponibles entre el 11 y 28 de octubre, se elige el 80% para realizar una Regresión Lineal Simple, considerando los datos SINCA como la referencia. Se obtienen, para cada sensor, 3 RLS en total, considerando los 3 rangos de temperatura definidos.

○

- El 20% de datos restantes se guarda para realizar una prueba de los resultados de la RLS.

A continuación se muestran los resultados de esta calibración basada en los datos SINCA, en conjunto con los comportamientos observados con los parámetros de calibración obtenidos en laboratorio, así como los resultados de las correlaciones observadas entre las series de referencia (SINCA) y los 5 módulos.

Las concentraciones asociadas a los sensores Alphasense no incluyen ningún tipo de corrección por temperatura, humedad u otro factor.

## 1. Monóxido de Nitrógeno

Los parámetros de calibración obtenidos en laboratorio para los sensores Alphasense NO-B4 de Monóxido de Carbono son los se encuentran en la Tabla 1. La Figura 1.1 muestra el período de estudio del 20% de las series de tiempo de prueba de los parámetros obtenidos con la calibración SINCA-Temperatura, en donde se observa un comportamiento amplificado de la señal del sensor Alphasense NO-B4 respecto a las concentraciones observadas en SINCA.

Sensor Alphasense NO-B4 | Pendiente | Intercepto | R2
1 | 0.00018 | 0.00929 | 1
2 | 0.00017 | 0.00229 | 1
3 | 0.00017 | -0.02953 | 0.999
4 | 0.00017 | -0.06014 | 1
5 | 0.00016 | -0.03664 | 1
6 | 0.00016 | -0.03933 | 1
Tabla 1: Parámetros de calibración de sensores Alphasense NO-B4 realizada en laboratorio.

hola

## Calibración SINCA-Temperatura

viernes, 17 de octubre de 2025 11:16

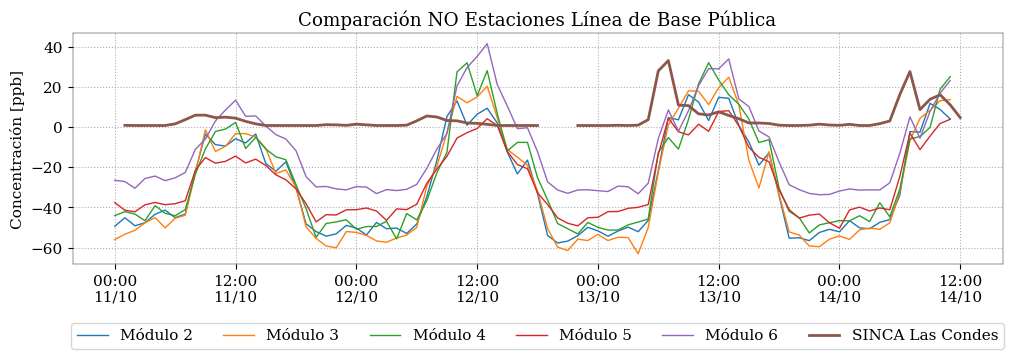
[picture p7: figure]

Figura 1.1: Comparación entre sensor Alphasense NO-B4 calculando concentraciones con parámetros de calibración de laboratorio y concentraciones NO medidas en estación SINCA.

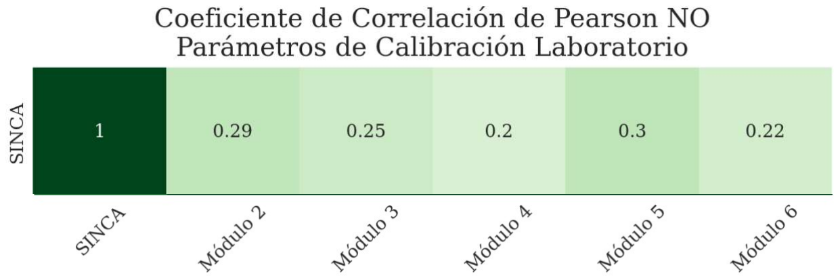
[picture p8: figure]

La Figura 1.2 muestra las regresiones realizadas por intervalos de temperatura para el monóxido de nitrógeno. A partir de estos parámetros se obtienen las concentraciones observadas en la Figura 1.3, en donde en función de la temperatura se utilizan los distintos parámetros de calibración para los sensores NO-B4.

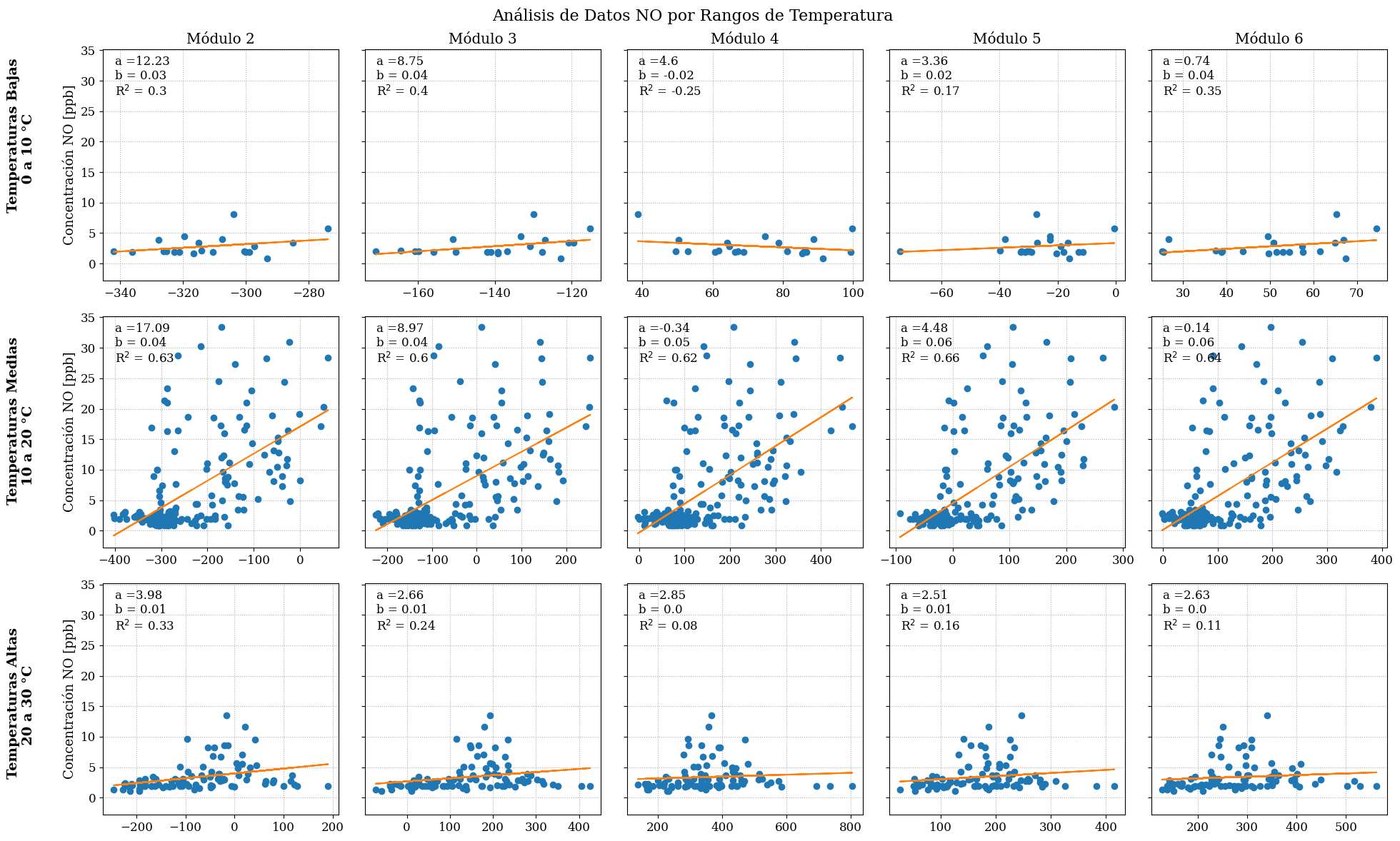
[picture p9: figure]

Figura 1.2: Resultados de Regresión Lineal Simple Alphasense NO-B4 vs. SINCA Las Condes, separando en 3 rangos de temperatura.

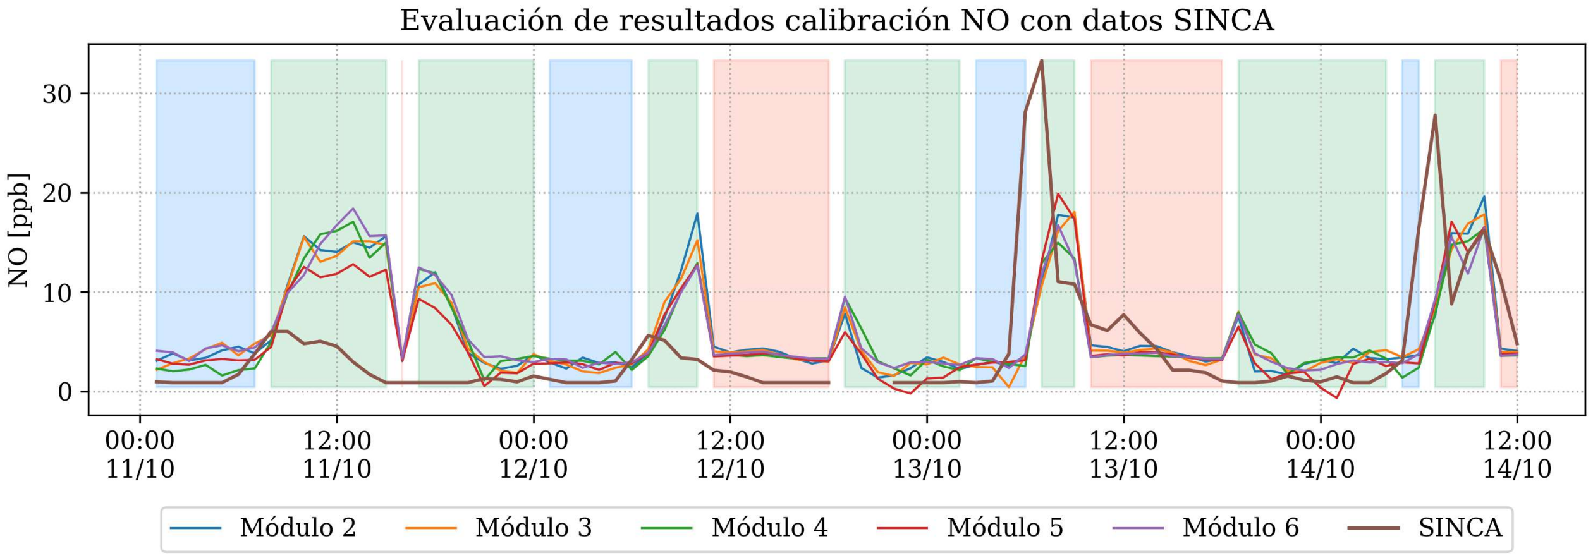
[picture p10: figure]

Figura 1.3: Comparación entre sensor Alphasense NO-B4 calculando concentraciones con Calibración SINCA- Temperatura. Serie de tiempo de 20% de datos considerados para prueba.

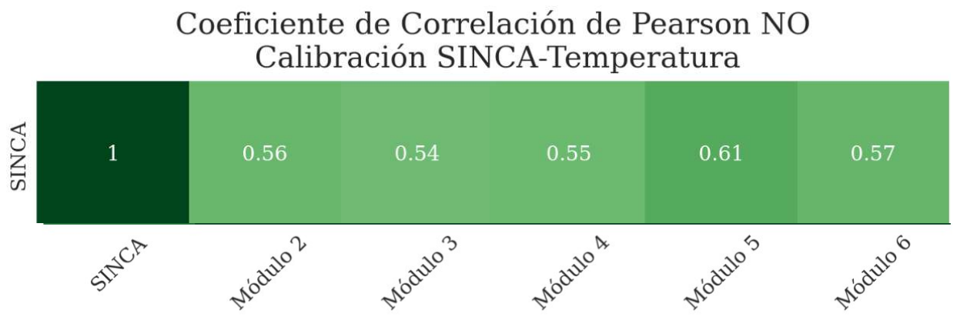
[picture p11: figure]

La comparación entre los coeficientes de correlación de Pearson indican una mejora con la metodología propuesta en la calibración SINCA-Temperatura para los 5 módulos instalados para este análisis. Es interesante notar que la mejora en las correlaciones cambia de manera distinta entre los 5 sensores, sin embargo, el Módulo 5 muestra la correlación más alta para ambos casos.

## 2. Dióxido de Nitrógeno

Los parámetros de calibración obtenidos en laboratorio para los sensores Alphasense NO2-B43F de Dióxido de Carbono son los se encuentran en la Tabla 2. La Figura 2.1 muestra el período de estudio del 20% de la serie de tiempo, dejada como test de la calibración SINCA-Temperatura a realizar, sólo que esta Figura utiliza los parámetros de la Tabla 2.

Sensor Alphasense NO2-B43F [ppb] | Pendiente | Intercepto | R2
1 | 0.62036 | 273.4671 | 0.993
2 | 0.59329 | 148.90783 | 0.993
3 | 0.57631 | 195.2833 | 0.993
4 | 0.59033 | 145.73665 | 0.994
5 | 0.65508 | 85.20131 | 0.999
6 | 0.66944 | 159.34674 | 0.999
Tabla 2: Parámetros de calibración de sensores Alphasense NO2-B43F realizada en laboratorio.

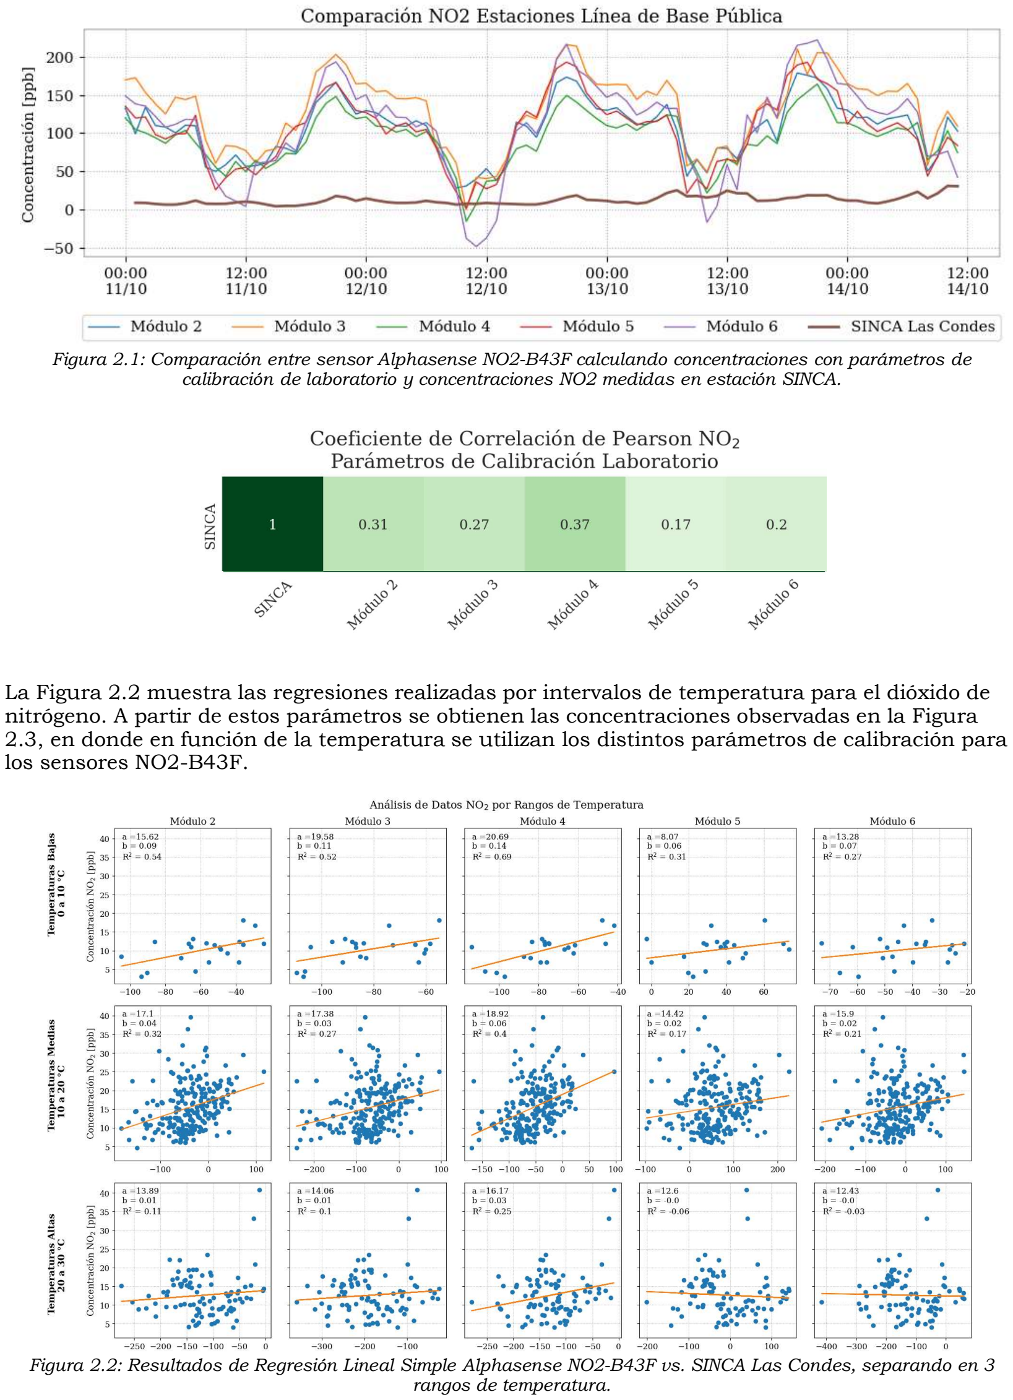
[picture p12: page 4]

Figura 2.1: Comparación entre sensor Alphasense NO2-B43F calculando concentraciones con parámetros de calibración de laboratorio y concentraciones NO2 medidas en estación SINCA.

La Figura 2.2 muestra las regresiones realizadas por intervalos de temperatura para el dióxido de nitrógeno. A partir de estos parámetros se obtienen las concentraciones observadas en la Figura 2.3, en donde en función de la temperatura se utilizan los distintos parámetros de calibración para los sensores NO2-B43F.

Figura 2.2: Resultados de Regresión Lineal Simple Alphasense NO2-B43F vs. SINCA Las Condes, separando en 3 rangos de temperatura.


Figura 2.3: Comparación entre sensor Alphasense NO2-B43F calculando concentraciones con Calibración SINCA- Temperatura. Serie de tiempo de 20% de datos considerados para prueba.


La comparación entre los coeficientes de correlación de Pearson indican una mejora con la metodología propuesta en la calibración SINCA-Temperatura para los 5 sensores NO2-B43F de este análisis. En este caso, los módulos 4 y 5 muestran mayores aumentos de correlación que los otros 3 módulos con esta calibración, sin embargo, los 5 módulos muestran la misma jerarquía en las correlaciones de antes y después de esta calibración.

## 3. Ozono

La Tabla 3 muestra los parámetros de calibración de laboratorio para cada uno de los 6 sensores Alphasense OX-B431, mientras que las Figuras 3.1 y 3.2 muestran la misma serie de tiempo, comparando las concentraciones de ozono obtenidas con estos parámetros de calibración, las concentraciones del módulo 6 en la Figura 3.1 muestran comportamientos similares a los otros 4 módulos en la Figura 3.2, sólo que a una escala significativamente mayor.

Sensor Alphasense OX-B431 O3 [ppm] | Pendiente | Intercepto | R2
1 | 0.00033 | 0.08866 | 0.999
2 | 0.00046 | 0.15158 | 0.997
3 | 0.00029 | -0.02163 | 0.998
4 | 0.00035 | 0.10523 | 0.998
5 | 0.00032 | 0.07544 | 1
6 | 0.08638 | 0.0003 | 1
Tabla 3: Parámetros de calibración de sensores Alphasense OX-B431 realizada en laboratorio.


Figura 3.1: Comparación entre sensor Alphasense OX-B431 calculando concentraciones con parámetros de calibración de laboratorio y concentraciones O3 medidas en estación SINCA. Sensores 2 a 6.


Figura 3.2: Comparación entre sensor Alphasense OX-B431 calculando concentraciones con parámetros de calibración de laboratorio y concentraciones O3 medidas en estación SINCA. Sensores 2 a 5.


La Figura 3.3 muestra las regresiones realizadas por intervalos de temperatura utilizando las concentraciones de ozono medidas en la estación SINCA. A partir de estos parámetros se obtienen las concentraciones observadas en la Figura 3.4, en donde en función de la temperatura se utilizan los distintos parámetros de calibración para los sensores OX-B431 y se contrastan con las concentraciones observadas en SINCA.


Figura 3.3: Resultados de Regresión Lineal Simple Alphasense OX-B431 vs. SINCA Las Condes, separando en 3 rangos de temperatura.

Figura 3.4: Comparación entre sensor Alphasense OX-B431 calculando concentraciones con Calibración SINCA- Temperatura. Serie de tiempo de 20% de datos considerados para prueba.

La comparación entre los coeficientes de correlación de Pearson indican una mejora visible con la metodología propuesta en la calibración SINCA-Temperatura para los 5 sensores OX-B431 de este análisis.

## 4. Monóxido de Carbono

La Tabla 4 muestra los parámetros de calibración de laboratorio para cada uno de los 6 sensores Alphasense CO-B4. La Figura 4.1 muestra el período de estudio del 20% de la serie de tiempo, dejada como test de la calibración SINCA-Temperatura a realizar, sólo que esta Figura utiliza los parámetros de la Tabla 4.

Sensor Alphasense CO-B4 [ppm] | Pendiente | Intercepto | R2
1 | 0.00014 | -0.19082 | 0.991
2 | 0.0001 | -0.11473 | 0.990
3 | 0.00023 | 0.11404 | 0.999
4 | 0.00027 | 0.20174 | 0.999
5 | 0.00007 | -0.06684 | 0.992
6 | 0.00008 | -0.00158 | 0.992

Tabla 4: Parámetros de calibración de sensores Alphasense CO-B4 realizada en laboratorio.


Figura 4.1: Comparación entre sensor Alphasense CO-B4 calculando concentraciones con parámetros de calibración de laboratorio y concentraciones CO medidas en estación SINCA.


La Figura 4.2 muestra las regresiones realizadas por intervalos de temperatura utilizando las concentraciones de monóxido de carbono medidas en la estación SINCA. A partir de estos parámetros se obtienen las concentraciones observadas en la Figura 4.3, en donde en función de la temperatura se utilizan los distintos parámetros de calibración para los sensores CO-B4 y se contrastan con las concentraciones observadas en SINCA.


Figura 4.2: Resultados de Regresión Lineal Simple Alphasense CO-B4 vs. SINCA Las Condes, separando en 3 rangos de temperatura.


Figura 4.3: Comparación entre sensor Alphasense CO-B4 calculando concentraciones con Calibración SINCA- Temperatura. Serie de tiempo de 20% de datos considerados para prueba.


Los sensores CO-B4 mostraron una reducción en la correlación entre las concentraciones SINCA y las estimaciones realizadas con la calibración SINCA-Temperatura, y a juzgar por las series de tiempo de concentraciones observadas en las Figuras 4.1 y 4.3, para este contaminante en particular puede que sea preferible una corrección calculada a partir del offset observado entre las concentraciones medidas por los módulos 3 y 4 en la Figura 4.1, en vez de aplicar esta calibración SINCA-Temperatura.

Conclusión.

La calibración usando como referencia los datos de la estación SINCA Las Condes muestra mejoras en las correlaciones de los sensores Alphasense NO-B4, NO2-B43F y OX-B431 mostrando mejoras en las estimaciones de concentraciones y corrigiendo la diferencia de magnitudes entre las concentraciones de ozono para el módulo 6. Para el sensor CO-B4 la calibración SINCA- Temperatura no muestra mejoras en la estimación de concentraciones de monóxido de carbono.

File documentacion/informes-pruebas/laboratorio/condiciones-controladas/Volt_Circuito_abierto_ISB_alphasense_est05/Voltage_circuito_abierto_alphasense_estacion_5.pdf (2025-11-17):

# Medición de Offset Electrónico

### (Open Circuit Voltage – OCV)


Figure 1: Placa Alphasense ISB

Responsable: Luis Gómez (luis.gomez@udd.cl) Revisores: Alejandro Rebolledo (arebolledo@udd.cl) Lugar: Laboratorio de Electrónica C+ — UDD, Santiago Fecha: 11 noviembre 2025 (10:00–13:52)
Estación evaluada: Estación 5
Proyecto: Linea base pública para la región metropolitana

### Propósito del Test

El objetivo del ensayo fue cuantificar el offset electrónico intrínseco generado por la placa Alphasense ISB cuando opera sin sensor conectado (condición de circuito abierto). Este voltaje corresponde exclusivamente a la acción de la electrónica interna del módulo (amplificadores, referen-cias y filtros) y constituye el valor base que debe restarse a las mediciones reales del sensor para separar:

- el offset electrónico (WEe, AEe),
- el offset propio del sensor (WEo, AEo).

Según la documentación técnica de Alphasense, el rango típico esperado para los canales OP1 (WE) y OP2 (Aux) se encuentra entre 200 y 300 mV (ver figura).


Figure 2: Conexiones ISB Alphasense ISB

### Procedimiento

Condiciones del ensayo (sin sensor B4)

- Alimentación aplicada: 3.5–6.5 VDC (fuente de bajo ruido).
- Medición de las señales OP1 (WE) y OP2 (Aux).
- Evaluación exclusivamente del offset electrónico en estado de circuito abierto.

Equipamiento

- Power Profile Kit II (fuente de alimentación de bajo ruido).
- Osciloscopio GW Instek GDS-12028.
- Multímetro Keysight 34461A.


(a) Fuente de alimentación | (b) Multímetro Keysight | (c) Osciloscopio GW Instek

Figure 3: Equipamiento utilizado en el ensayo: fuente de bajo ruido, multímetro y osciloscopio.

Procedimiento medición aplicado a cada placa ISB

- Se extrae el sensor del socket de la placa Alphasense ISB. Esto podria no ser recomendable ya que se podría perder la calibración de fabrica.
- Se conectan los cables según diagrama de la figura 4 y 5.
- Se conecta el terminal GND de la placa ISB al terminal negativo de la fuente de bajo ruido.
- Se conectan las tierras de los canales 1 y 2 del osciloscopio al GND de la placa.

- Se conectan OP1+ y OP2+ a las puntas de prueba de los canales 1 y 2 del osciloscopio, respectivamente.
- Se enciende la fuente de alimentación.
- Tras un tiempo de estabilización de 1 segundo, se conecta el terminal positivo de la fuente al pin V+ de la ISB.
- Se realizan las mediciones con osciloscopio y multímetro.
- Se apaga la fuente de alimentación y se desconecta la placa.

Este procedimiento se repitió para cinco placas ISB diferentes, identificadas como DBI 01 a DBI 05 mediante etiquetas adhesivas.


Figure 4: Conexiones de la prueba de Offset

GND común

Vfuente

V+

GND fuente

ISB (Molex)

V+ IN

GND ISB

OP1+

OP2+

Osciloscopio
Ch1 (+)

Ch2 (+)

GND osc.

Figure 5: Esquema de conexiones electrónicas para la medición de offset en la ISB.

### Resultados

Mediciones con multímetro (TESTER)

Resultados obtenidos mediante mediciones con osciloscopio (ver tabla 1)

Table 1: Valores medidos con multímetro (OP1 y OP2 en condición de circuito abierto).

DBI | Gas | OP1+ (mV) OP2+ (mV)
01 | CO | 352 | 341
02 | NO2 | 236 | 237
03 | NO | 273 | 277
04 | OX | 231 | 242
05 | SO2 | 354 | 359

Mediciones con osciloscopio

Resultados obtenidos mediante mediciones con osciloscopio (ver tabla 2 y´ figura 6)

Table 2: Valores de OP1+ y OP2+ medidos con osciloscopio durante la prueba de offset electrónico.

DBI | Gas | OP1+ (mV) OP2+ (mV)
01 | CO | 375 | 370
02 | NO2 | 267 | 272
03 | NO | 312 | 320
04 | OX | 257 | 270
05 | SO2 | 384 | 397


Figure 6: salida osciloscopio de una de las pruebas para OP1+ y OP2+

### Análisis

Las mediciones obtenidas con multímetro presentan una señal estable y con menor efecto del ruido eléctrico, por lo que representan una mejor estimación del offset electrónico en estado estacionario. Los valores correspondientes a NO2, NO y OX se encuentran dentro del rango esperado (200–300 mV). En contraste, las placas asociadas a CO y SO2 presentan offsets superiores, aunque los valores son estables y coherentes entre OP1 y OP2, indicando un comportamiento normal de la electrónica del módulo.
Las mediciones con osciloscopio son ligeramente mayores debido a:
- sensibilidad al ripple de la alimentación,
- captura de transientes breves,
- menor impedancia de entrada en comparación al multímetro.

### Conclusiones

- Las mediciones realizadas con multímetro se recomiendan para establecer los valores finales de offset electrónico WEe y AEe.
- No se observaron signos de saturación, fallas en amplificadores ni comportamientos anómalos en las placas ISB.
- Los valores caracterizados pueden ser utilizados directamente como parte del proceso de corrección electrónica previo al cálculo de concentración.

### Recomendaciones

Para mejorar futuros ensayos, se recomienda:

- añadir capacitores de desacople adicionales en la salida de la ISB para reducir el ruido,
- realizar un muestreo temporal prolongado y calcular la desviación estándar del offset,
- blindar cables de conexión,
- controlar la temperatura de la sala, ya que el offset de la electrónica presenta dependencia térmica.
- Medir con sensor conectado y sin gas para comparar el offset electrónico con el offset total (electrónico + sensor).
- Realizar mediciones de corriente, con y sin sensor, para evaluar el consumo en estado de circuito abierto.
- Armar pares de placa y sensor y no separarlos.

——————————————————-

### References

[1] Alphasense Ltd. 4-Electrode Individual Sensor Board (ISB) User Manual. Issue 7, Document 085-2217, Great Notley, Essex, UK, 2019.

[2] Alphasense Ltd. AAN 803-05: Correcting for Background Currents in Four-Electrode Toxic Gas Sensors. Application Note, 2019.
[3] Alphasense Ltd. B4-Series Toxic Gas Sensors: Specifications. Sensor Technology House, Great Notley, Essex, UK, 2019.
[4] Keysight Technologies. Keysight 34461A Truevolt 6½ Digit Multimeter – User’s Guide. 2020.
[5] GW Instek. GDS-12000 Series Digital Oscilloscopes – User Manual. 2021.
[6] Nordic Semiconductor. Power Profiler Kit II – User Guide. 2023.

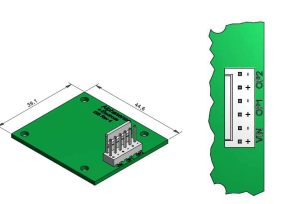
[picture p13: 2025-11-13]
documentacion/informes-pruebas/laboratorio/condiciones-controladas/Volt_Circuito_abierto_ISB_alphasense_est05/img/Conexiones_ISB.png

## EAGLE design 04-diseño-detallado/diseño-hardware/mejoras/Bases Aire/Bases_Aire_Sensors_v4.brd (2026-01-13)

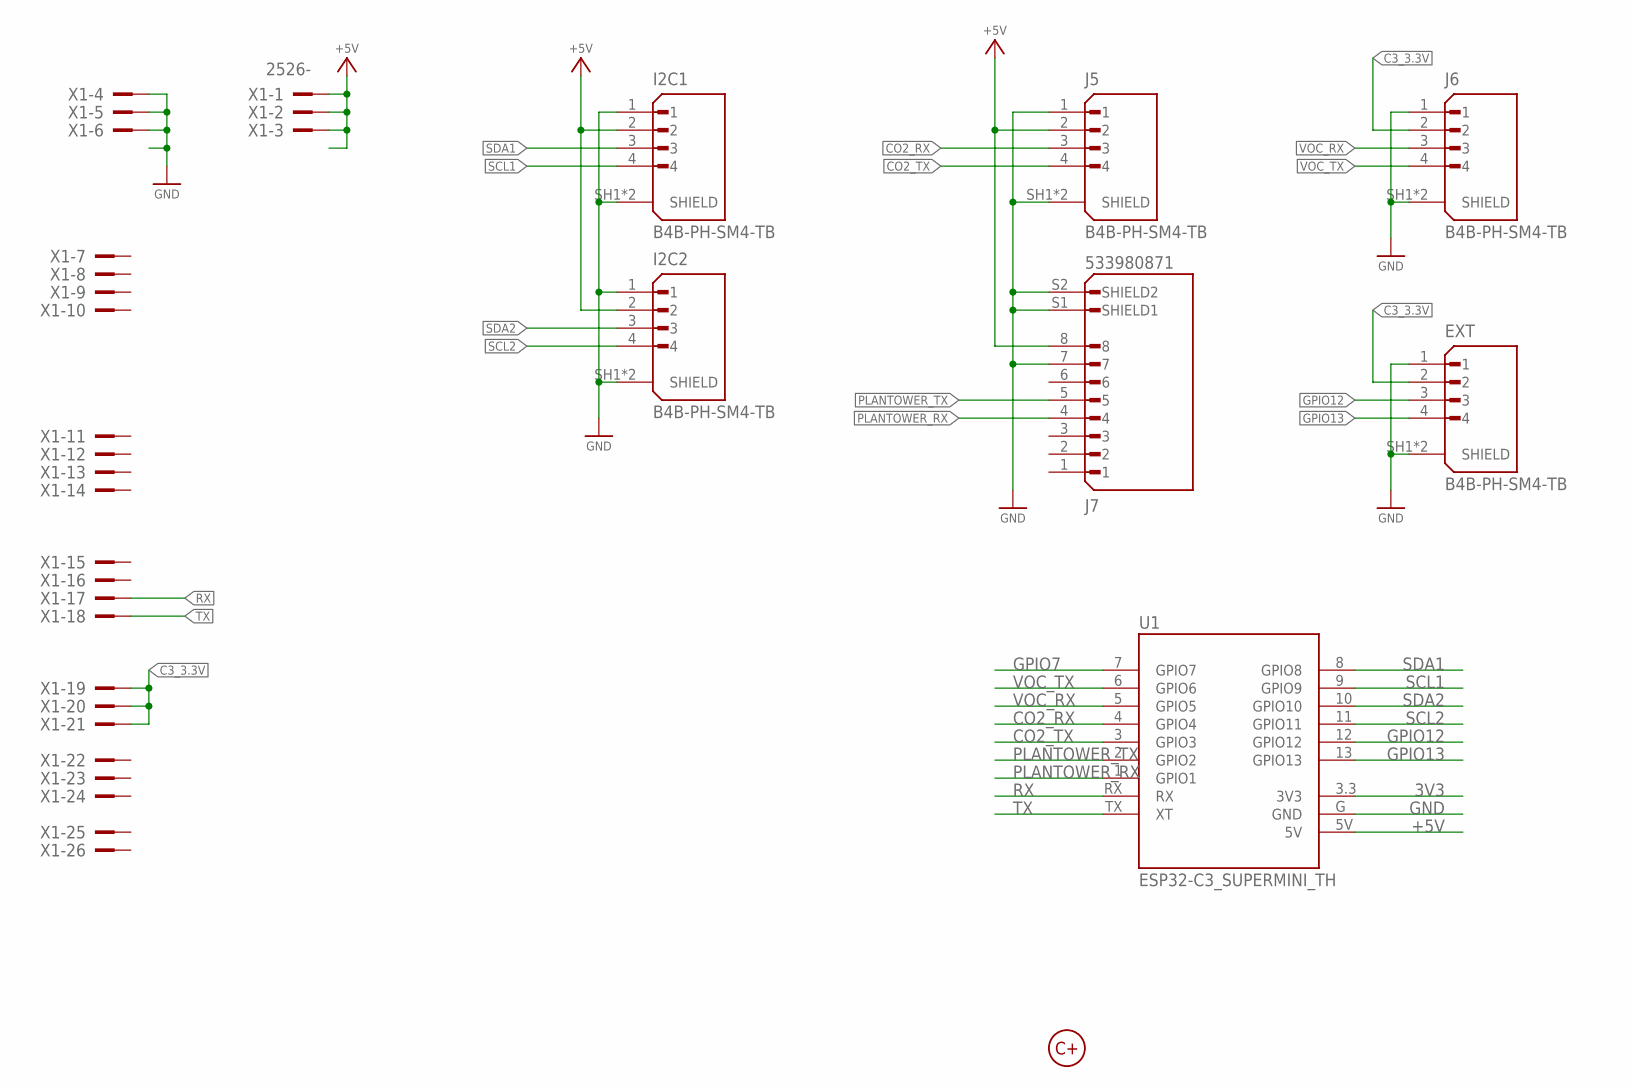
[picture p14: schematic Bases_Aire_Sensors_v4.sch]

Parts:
EXT: B4B-PH-SM4-TB; JST_B4B-PH-SM4-TB
I2C1, I2C2: B4B-PH-SM4-TB; JST_B4B-PH-SM4-TB
J5, J6: B4B-PH-SM4-TB; JST_B4B-PH-SM4-TB
J7: 533980871; MOLEX_533980871
U1: ESP32-C3_SUPERMINI_TH; MODULE_ESP32-C3_SUPERMINI_TH
U$1: LOGO_CMAS10MM; LOGO_10MM
X1: 2526-; PAK100/2500-26

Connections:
3V3: U1.3.3 (3V3)
+5V: I2C1.2, I2C2.2, J5.2, J7.8, U1.5V, X1.1, X1.2, X1.3
C3_3.3V: EXT.2, J6.2, X1.19, X1.20, X1.21
CO2_RX: J5.3, U1.4 (GPIO4)
CO2_TX: J5.4, U1.3 (GPIO3)
GND: EXT.1, EXT.SH1 (SHIELD), EXT.SH2 (SHIELD), I2C1.1, I2C1.SH1 (SHIELD), I2C1.SH2 (SHIELD), I2C2.1, I2C2.SH1 (SHIELD), I2C2.SH2 (SHIELD), J5.1, J5.SH1 (SHIELD), J5.SH2 (SHIELD), J6.1, J6.SH1 (SHIELD), J6.SH2 (SHIELD), J7.7, J7.S1 (SHIELD1), J7.S2 (SHIELD2), U1.G (GND), X1.4, X1.5, X1.6
GPIO7: U1.7 (GPIO7)
GPIO12: EXT.3, U1.12 (GPIO12)
GPIO13: EXT.4, U1.13 (GPIO13)
PLANTOWER_RX: J7.4, U1.1 (GPIO1)
PLANTOWER_TX: J7.5, U1.2 (GPIO2)
RX: U1.RX, X1.17
SCL1: I2C1.4, U1.9 (GPIO9)
SCL2: I2C2.4, U1.11 (GPIO11)
SDA1: I2C1.3, U1.8 (GPIO8)
SDA2: I2C2.3, U1.10 (GPIO10)
TX: U1.TX (XT), X1.18
VOC_RX: J6.3, U1.5 (GPIO5)
VOC_TX: J6.4, U1.6 (GPIO6)

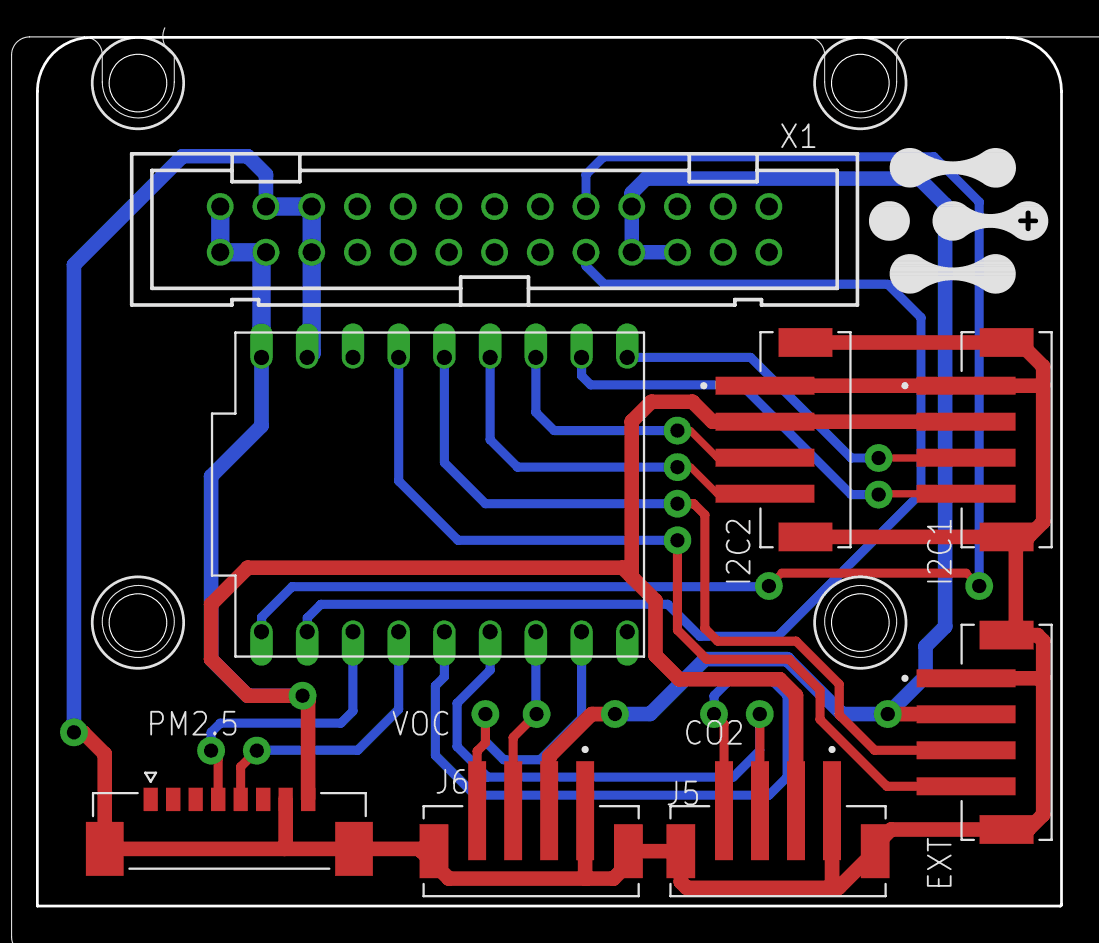
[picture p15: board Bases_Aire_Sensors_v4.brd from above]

Board: 2 copper layers, 56.9 x 48.3 mm, 9 parts (0 on the bottom side), 17 nets.

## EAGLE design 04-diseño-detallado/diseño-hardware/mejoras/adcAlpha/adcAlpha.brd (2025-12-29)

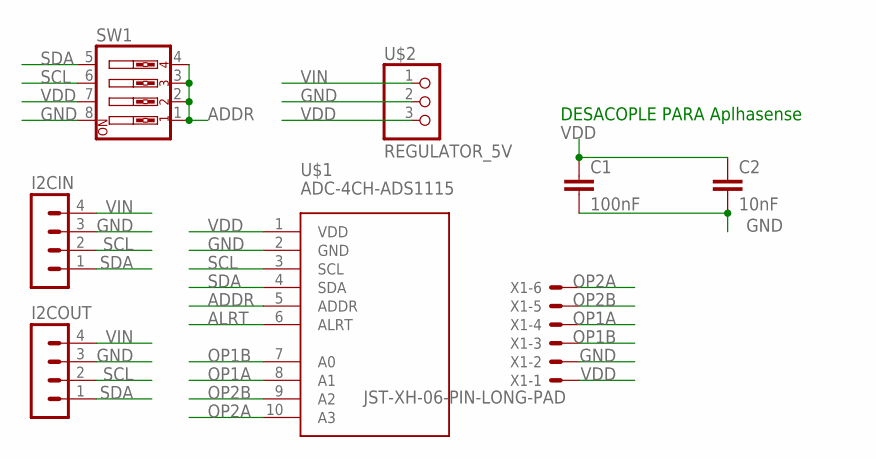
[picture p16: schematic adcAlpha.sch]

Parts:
C1: 100nF; CAP-PTH-SMALL-KIT
C2: 10nF; CAP-PTH-SMALL-KIT
I2CIN, I2COUT: MA04-1
SW1: SW_DIP-4; EDG-04
U$1: ADC-4CH-ADS1115
U$2: REGULATOR_5V; 1X03
X1: JST-XH-06-PIN-LONG-PAD; JST-XH-06-PACKAGE-LONG-PAD

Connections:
ADDR: SW1.1, SW1.2, SW1.3, SW1.4, U$1.5 (ADDR)
ALRT: U$1.6 (ALRT)
GND: C1.2, C2.2, I2CIN.3, I2COUT.3, SW1.8, U$1.2 (GND), U$2.2 (GND), X1.2
OP1A: U$1.8 (A1), X1.4
OP1B: U$1.7 (A0), X1.3
OP2A: U$1.10 (A3), X1.6
OP2B: U$1.9 (A2), X1.5
SCL: I2CIN.2, I2COUT.2, SW1.6, U$1.3 (SCL)
SDA: I2CIN.1, I2COUT.1, SW1.5, U$1.4 (SDA)
VDD: C1.1, C2.1, SW1.7, U$1.1 (VDD), U$2.3 (OUT5V), X1.1
VIN: I2CIN.4, I2COUT.4, U$2.1 (IN)

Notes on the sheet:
DESACOPLE PARA Aplhasense

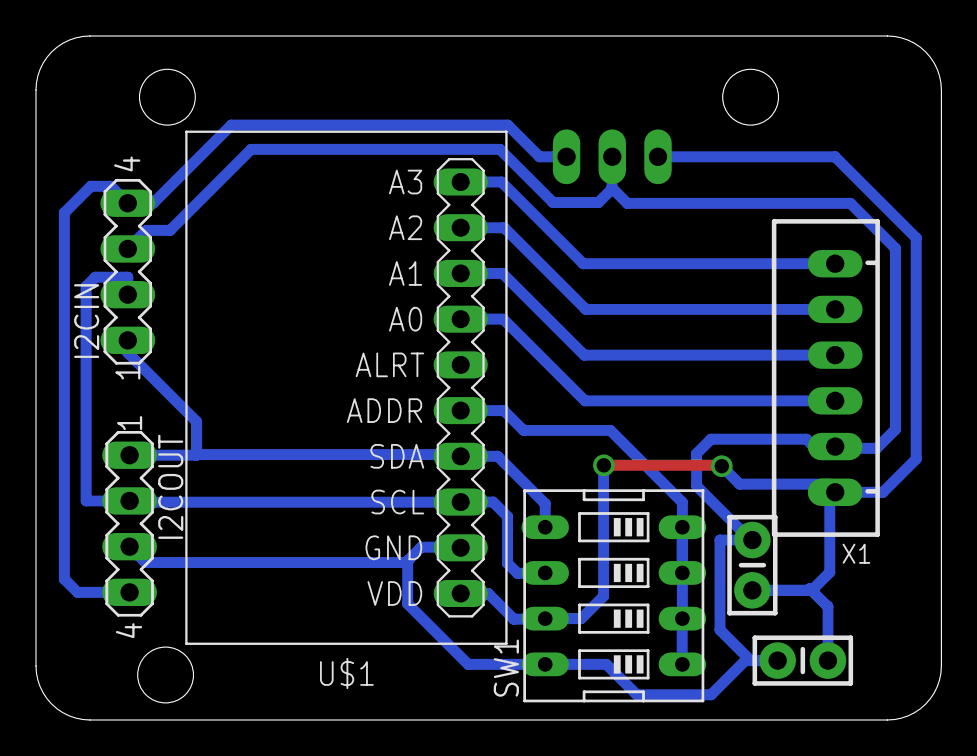
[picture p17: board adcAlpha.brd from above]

Board: 2 copper layers, 50.3 x 38.0 mm, 8 parts (1 on the bottom side), 10 nets.

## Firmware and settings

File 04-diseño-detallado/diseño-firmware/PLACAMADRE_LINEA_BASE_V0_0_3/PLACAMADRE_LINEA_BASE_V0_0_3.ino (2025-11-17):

/*
SD: timestamp(persona)fecha hora,BateriaEstacion,temperaturaEstacion,SEÑAL,adc2 CO raw OP1/CH3,CO rawOP2/ch4,adc2 N02 OP1/CH1 RAW,NO2 OP2/CH2,adc1 N0 OP1/CH3 RAW, NO OP2/CH4 RAW,adc1 OX OP1/CH1 RAW,OX OP2/CH2,PMS TEMP,PMS HUM,PMS 2.5,CO2_internal,CO2_RAW,CO2_CUSTOM,ESTACION TEMP,ESTACION HUM,ESTACION PRESION,VIENTO VELOCIDAD,VIENTO DIRECCION,LLUVIA ACUMULADA TOTAL,RADIACION TOTAL SOLAR,TOVC,SO2 RAW 
/*
 * Sistema de Monitoreo Ambiental (Placa Madre Rev. D)
 *
 * Autor: Alejandro Rebolledo
 * Revisión: 0.3
 * Fecha: 30 de julio del 2025
 *
 * Descripción general:
 * Este firmware implementa un sistema integrado para monitorear múltiples parámetros ambientales y climáticos.
 * Se encarga de adquirir datos desde diversos sensores (ADS1115, MH-Z19, PMS5003, sensores Modbus, TVOC, SO2, UV, etc.),
 * guardarlos en una tarjeta SD en formato CSV con timestamp, batería, calidad de señal y valores brutos de los sensores.
 * Además, envía datos periódicamente a través del módem GSM/LTE (SIM7600) hacia un servidor remoto.
 * El firmware gestiona también la captura, almacenamiento y envío periódico de imágenes capturadas mediante una cámara externa (interfaz serie).
 *
 * Características Principales:
 * - Lectura periódica y simultánea de múltiples sensores analógicos y digitales.
 * - Almacenamiento seguro en tarjeta SD con gestión robusta de archivos y directorios.
 * - Envío automático y periódico de datos al servidor remoto mediante protocolo HTTP usando módem SIM7600.
 * - Captura periódica y transmisión robusta de imágenes mediante comunicación UART con cámara externa.
 * - Uso eficiente de Watchdog (WDT) para asegurar estabilidad y auto-recuperación en caso de fallos.
 * - Control y monitoreo remoto del estado de la estación (batería, señal celular, calidad de sensores).
 * - Indicaciones visuales del estado del sistema mediante LED RGB.
 *
 * Estructura del código:
 * - Inicialización y verificación robusta de hardware y sensores.
 * - Manejo estructurado de máquina de estados para captura y envío de fotos.
 * - Verificación periódica y robusta de conectividad celular con reinicio automático del módem ante fallos persistentes.
 * - Optimización de consumo energético mediante control selectivo de encendido y apagado de periféricos.
 * - Gestión robusta de errores con almacenamiento en log dedicado en tarjeta SD.
 *
 * Consideraciones adicionales:
 * Este sistema está diseñado para monitoreo continuo en campo, garantizando estabilidad operativa y eficiencia energética.
 * Se recomienda verificar periódicamente el estado de sensores, almacenamiento SD y calidad de señal celular en terreno.
 */

#define firmwareVersion 0.0.3L

#define TINY_GSM_MODEM_SIM7600
#define TINY_GSM_RX_BUFFER 2014  // Set RX buffer to 2Kb
#define SerialAT Serial1

#include <esp_system.h>
#include "esp_adc_cal.h"  //better batt
#include "esp_task_wdt.h"
// --- Watchdog timeout (segundos) ---
const int WDT_TIMEOUT_S = 90;
#include <Wire.h>
#include <Adafruit_ADS1X15.h>
#include <Adafruit_NeoPixel.h>
#include "MHZ19.h"
#include <SoftwareSerial.h>
#include <ModbusMaster.h>
#include <Arduino.h>
//#include <StreamDebugger.h> //depreciado
#include <TinyGsmClient.h>
#include <U8g2lib.h>
#include <RTClib.h>
#include <ArduinoJson.h>
#include "FS.h"
#include "SD.h"
#include "SPI.h"
#define SD_CS_PIN 5  //para revision B es el 4 //el 5 revision D
//webserver rescate SD
#include <WiFi.h>
#include <WebServer.h>

WebServer server(80);
File uploadFile;
const char *ssid = "LINEABASE_EST01";
const char *password = "12345678";

// --- Transfer settings foto ---------------------------------------------------
#define CHUNK_SIZE 256
int RECEIVE_TIMEOUT = 45000;     // este timeoyt va a ser nas grande cuando lo intente por segunda vez solo para preubas
unsigned long lastByteTime = 0;  // To track last received byte time
bool sendAfterReceive = false;   // para reenviar foto
bool receiving = false;          //bool cuando esta recibiendo por serial
bool SavedSDafter = false;       // para asegurarse de que se guardo en la sd
File outFile;                    //tambien relacionado con el manejo de las fotos
String filename;                 //del archivo que se recepciona foto en la sd
int fileSize = 0;                //del string recibido para parsear el tama;o del archivo foto
int bytesReceived = 0;           //del manejo foto
String PHOTO_PATH = "";          // Ensure PHOTO_PATH is always initialized para mandar la foto por gsm
bool hasRetried = false;         //del manejo de fotos
bool photosenderOK = false;      //recibi ready de la rpi

//---conectividad                                                                                                                                                                                                                                           //direccion de testeo
const char *NGROK_URL = "https://hermit-harmless-wildly.ngrok-free.app/agregarImagen";                                                                                                                                                                                                                                                     //pruebas exitosas
//sensor 0 pruebas
//#define stationId 1 //
//const char *BASE_SERVER_URL = "http://api-sensores.cmasccp.cl/insertarMedicion?idsSensores=121,121,121,122,122,122,122,151,151,151,151,151,151,151,124,124,125,125,126,126,127,127,158,158,159,159,155,145,156,152,128,129&idsVariables=31,32,33,8,9,3,6,3,6,29,30,5,17,13,18,28,19,27,20,26,21,25,37,38,39,40,34,24,35,3,4,15&valores=";  //1,576,96,2,3,4,5,6,7,8,9,10,66,11,12,13,14,15,16,17,18,22,23,19,20,21"
//sensor 1 pendiente
//#define stationId 1 //origilanlemtne 1 esto cambia segun url
//const char *BASE_SERVER_URL = "http://api-sensores.cmasccp.cl/insertarMedicion?idsSensores=219,219,219,220,220,220,220,228,228,228,228,228,228,228,221,221,222,222,223,223,224,224,232,232,233,233,230,227,231,229,225,226&idsVariables=31,32,33,8,9,3,6,3,6,29,30,5,17,13,18,28,19,27,20,26,21,25,37,38,39,40,34,24,35,3,4,15&valores="; // ID1
//sensor 2 
//#define stationId 2 //originalemtne esta ya esta subida.
//const char *BASE_SERVER_URL = "http://api-sensores.cmasccp.cl/insertarMedicion?idsSensores=311,311,311,312,312,312,312,320,320,320,320,320,320,320,313,313,314,314,315,315,316,316,324,324,325,325,322,319,323,321,317,318&idsVariables=31,32,33,8,9,3,6,3,6,29,30,5,17,13,18,28,19,27,20,26,21,25,37,38,39,40,34,24,35,3,4,15&valores="; // ID2
//sensor 3
//#define stationId 3 //originalemtne esta ya esta subida.
//const char *BASE_SERVER_URL = "http://api-sensores.cmasccp.cl/insertarMedicion?idsSensores=326,326,326,327,327,327,327,335,335,335,335,335,335,335,328,328,329,329,330,330,331,331,339,339,340,340,337,334,338,336,332,333&idsVariables=31,32,33,8,9,3,6,3,6,29,30,5,17,13,18,28,19,27,20,26,21,25,37,38,39,40,34,24,35,3,4,15&valores="; // ID3
//sensor 4
//#define stationId 4 //originalemtne esta ya esta subida.
//const char *BASE_SERVER_URL = "http://api-sensores.cmasccp.cl/insertarMedicion?idsSensores=341,341,341,342,342,342,342,350,350,350,350,350,350,350,343,343,344,344,345,345,346,346,354,354,355,355,352,349,353,351,347,348&idsVariables=31,32,33,8,9,3,6,3,6,29,30,5,17,13,18,28,19,27,20,26,21,25,37,38,39,40,34,24,35,3,4,15&valores="; // ID4
//sensor 5
//#define stationId 5 //originalemtne esta ya esta subida.
//const char *BASE_SERVER_URL = "http://api-sensores.cmasccp.cl/insertarMedicion?idsSensores=356,356,356,357,357,357,357,365,365,365,365,365,365,365,358,358,359,359,360,360,361,361,369,369,370,370,367,364,368,366,362,363&idsVariables=31,32,33,8,9,3,6,3,6,29,30,5,17,13,18,28,19,27,20,26,21,25,37,38,39,40,34,24,35,3,4,15&valores="; // ID5
//sensor 6
#define stationId 6 //originalemtne esta ya esta subida.
const char *BASE_SERVER_URL = "http://api-sensores.cmasccp.cl/insertarMedicion?idsSensores=371,371,371,372,372,372,372,380,380,380,380,380,380,380,373,373,374,374,375,375,376,376,384,384,385,385,382,379,383,381,377,378&idsVariables=31,32,33,8,9,3,6,3,6,29,30,5,17,13,18,28,19,27,20,26,21,25,37,38,39,40,34,24,35,3,4,15&valores="; // ID6



#define uS_TO_S_FACTOR 1000000ULL  // Factor de conversión de microsegundos a segundos
#define TIME_TO_SLEEP 30           // Tiempo de sleep en segundos
#define UART_BAUD 115200

//---------------uart modem
#define MODEM_RX_PIN 17
#define MODEM_TX_PIN 16

//StreamDebugger debugger(SerialAT, Serial);//eliminamos debugg
//TinyGsm modem(debugger); activamos el debug
TinyGsm modem(SerialAT);
TinyGsmClient client(modem);


// --- GPRS & Webhook config -----------------------------------------------
const char *APN = "gigsky-02";
const char *GPRS_USER = "";
const char *GPRS_PASS = "";
String networkOperator;
String networkTech;
String signalQuality;
String registrationStatus;
String lastPostedID;
//modem helpers
bool httpSessionActive = false;
String lastAtCommand;
String httpReadData;

// — Máximo de strikes antes de reiniciar el módem
const int MAX_MODEM_STRIKES = 10;
int ModemStrikes = 0;

// —— Pin definitions ——
const int SENSOR_POWER_PIN = 4;
const int CAM_POWER_PIN = 25;
const int MODEM_POWER_PIN = 13;

// bat formulae Divider resistor values (in kilo-ohms)
// --- Pin y divisor ---
#define BATT_SENSE_PIN 36  // ADC1_CH0 en GPIO36
const float R1 = 470.0;    // top resistor (kΩ)
const float R2 = 100.0;    // bottom resistor (kΩ)
// --- Parámetros ADC ---
const uint32_t DEFAULT_VREF = 1100;  // mV, ajústalo si mides otra cosa
esp_adc_cal_characteristics_t adc_chars;

// --- Serial port pins ---------------

// CAMARA
#define FILE_RX_PIN 35
#define FILE_TX_PIN 26
SoftwareSerial fileSerial(FILE_RX_PIN, FILE_TX_PIN);
#define CAMBAUD 31250
// —— ADS1115 instances ——
Adafruit_ADS1115 ads1;  // address 0x48
Adafruit_ADS1115 ads2;  // address 0x49
Adafruit_ADS1115 ads3;  // address 0x4A
// —— MH-Z19 CO₂ sensor ——
#define MHZ19_RX_PIN 34
#define MHZ19_TX_PIN 32
SoftwareSerial co2Serial(MHZ19_RX_PIN, MHZ19_TX_PIN);
MHZ19 co2Sensor;

// —— PMS5003 particulate sensor ——
const int PMS_RX_PIN = 39;
const int PMS_TX_PIN = 33;
SoftwareSerial pmsSerial(PMS_RX_PIN, PMS_TX_PIN);
uint8_t pmsBuffer[32];

// —— Modbus wind sensor ——
const int DE_PIN = 14;
const int RE_PIN = 14;
const int RS485_RX_PIN = 27;
const int RS485_TX_PIN = 15;
SoftwareSerial rs485Serial(RS485_RX_PIN, RS485_TX_PIN);
ModbusMaster modbus;

// --- RTC & rgb -----------------------
U8G2_SH1107_SEEED_128X128_F_HW_I2C display(U8G2_R0);
RTC_DS3231 rtc;

#define RGB_PIN 2     // Pin where your NeoPixel is connected
#define NUM_PIXELS 1  // Número de LEDs en la tira

const int rgbPowerPin = GPIO_NUM_12;
Adafruit_NeoPixel pixels(NUM_PIXELS, RGB_PIN, NEO_GRB + NEO_KHZ800);

// —— Global variables for readings ——
String fileCSV;      //ruta del csv
String logFilePath;  // ruta del log
// ADC readings
float adc1Raw[4];
float adc2Raw[4];
float adc3Raw[4];
// CO₂ readings
double co2Ppm;
double co2Raw;
double co2Custom;

// PMS5003 readings
uint16_t pm1, pm25, pm10;
float pmsTemp, pmsHum;

// Wind sensor readings
uint8_t modbusResult;
float windSpeed;
uint16_t windStrength, windDirection;
float windHumidity, windTemperature, windPressure;
float windRainfall, windSolarIrradiance;
// UV
float uvIntensity_mWcm2 = 0.0;
uint16_t uvIndex = 0;

// I²C payload buffer
const uint8_t I2C_SLAVE_ADDR = 0x08;
char i2cBuf[33];
uint8_t i2cBytes, i2cBufLen;
float so2Ppm;
uint16_t tvocValue;
// factores internos, temperatura rtc y bateria
float stationTemperature;
float batteryLevel;
float signalValue;  ////////////es del modem
// —— Timing globals ——
unsigned long prevLoopMillis = 0;
const unsigned long LOOP_INTERVAL_MS = 1000 * 20;  //registradatos

unsigned long SaveMillis = 0;
const unsigned long SAVE_INTERVAL_MS = 1000 * 60;  //guarda datos

unsigned long SaveFotoMillis = 0;
const unsigned long FOTO_INTERVAL_MS = 1010 * 60 * 60 * 3;  //guarda y manda foto ca 3 hora ligero desfase para no topar con el envio de datos cad 5 minutos

unsigned long SendMillis = 0;
const unsigned long SEND_INTERVAL_MS = 1000 * 60 * 5;  //manda datos

// --- State variables ------------------------------------------------------
const unsigned long networkInterval = 60000 * 30;  // revisa si esta conectado, puede que tope, revisar
unsigned long lastNetworkUpdate = 0;               // chequear conecxion

//----------Global bools for control-----------------
bool clientConnected = false;  // Variable para indicar si hay una conexión activa WIFI
const bool DEBUG = true;       // Debug flag para seriales del wifi
bool requestedfoto = false;    // se solicito foto control de estructura maquina de estados
bool savedSD = false;          //guardando evita las otras funciones mauqina de estado
bool sending = false;          //mandando por gsm control de estado
bool leyendoDatos = false;     // leyendo sensores control de estados
int strikes = 0;               //reintentos de la camara
bool FirstRun = true;
bool SDOK = false;
bool RTCOK = false;
bool ADC1 = false;
bool ADC2 = false;
bool ADC3 = false;
bool RS485METEO = false;
bool RS485UV = false;
bool I2CTVOCYSo2 = false;
bool PLANTOWER = false;
bool Co2 = false;
// --- Global raw sensor values ---
// ADC1 channels
float adc1OxOp1Ch1Raw;
float adc1OxOp2Ch2Raw;
float adc1NoOp1Ch3Raw;
float adc1NoOp2Ch4Raw;
// ADC2 channels
float adc2No2Op1Ch1Raw;
float adc2No2Op2Ch2Raw;
float adc2CoOp1Ch3Raw;
float adc2CoOp2Ch4Raw;
// ADC3 channels
float adc3So2Op1Ch1Raw;
float adc3So2Op2Ch2Raw;
float adc3XXOp1Ch3Raw;
float adc3XXOp2Ch4Raw;
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
void loop() {
  handlePowerCycleModem();  //maquina de estados para reiniciar el modem en caso de muchos problemas de envio
  unsigned long now = millis();
  // --- Alimenta al watchdog antes de que expire ---
  esp_task_wdt_reset();    //reset watchdog
  handleSerialCommands();  //serialcomands para debugear revisar pestaña SerialComands
  readModemResponses();    //parsea los mensajes del MODEM Revisar pestaña gsm

  if (FirstRun == true) {
    updateNetworkInfo();
    digitalWrite(CAM_POWER_PIN, HIGH);  //prender la camara
    Serial.println("Prendida la camara");
    FirstRun = false;
  }
  if (ModemStrikes >= MAX_MODEM_STRIKES) {
    beginPowerCycleModem();
  }
  // if (leyendoDatos == false && savedSD == false && sending == false) {  //funcion vieja si vuelve el wifi
  //   // clientConnected = (WiFi.softAPgetStationNum() > 0); //desactivado por problemas de ADC
  // }
  // if (clientConnected) {
  //   //esta funciuon no se implementara en esta version por problemas de consumo
  //   // digitalWrite(rgbPowerPin, HIGH);
  //   // pixels.setPixelColor(0, pixels.Color(0, 15, 15));
  //   // pixels.show();
  //   //server.handleClient(); //desactivado
  //   // ensureAP();
  //   yield();
  // } else {

  /////ahora esto es main
  checkReadyTimeout();  //timeout de la camara la apaga si o si en 3 minutos
  // —— Main loop interval ——
  if (!receiving && fileSerial.available()) {
    readHeader();
    yield();
  }
  // 2) Si estamos recibiendo, proceso la recepción y salgo
  else if (receiving) {
    processReception();
    return;
  }

  if (requestedfoto == false && savedSD == false && sending == false && receiving == false) {
    leyendoDatos = true;

    if (sendAfterReceive && SavedSDafter) {
      Serial.println("Sending image after receive...");
      sendImageWebhook();
      sendAfterReceive = false;
      SavedSDafter = false;
    }

    if (now - prevLoopMillis >= LOOP_INTERVAL_MS) {
      prevLoopMillis = now;
      //battery
      Serial.print("Operador: " + networkOperator);
      Serial.print(" Tecnología: " + networkTech);
      Serial.print(" señal CSQ: " + signalQuality);
      Serial.println(" Conectado: " + registrationStatus);


      uint32_t raw = analogRead(BATT_SENSE_PIN);
      uint32_t vSense_mV = esp_adc_cal_raw_to_voltage(raw, &adc_chars);

      float vSense = vSense_mV / 1000.0f;
      batteryLevel = vSense * ((R1 + R2) / R2);
      Serial.println("V bateria: " + String(batteryLevel));

      updateRawValues();  // populate your globals
      printRawValues();   // dump to serial

      // 2) Read MH-Z19 CO2
      co2ReadSensor();
      // 3) Read PMS5003
      pmsReadSensor();
      // 4) Read wind sensor via Modbus
      delay(30);
      readWindSensor();  // ID 1
      delay(30);
      readUVSensor();  // ID 2
                       // i2c EXTERNO VOC
                       // --- I²C external sensor (TVOC + SO2) ---
      if (isDeviceConnected(I2C_SLAVE_ADDR)) {
        I2CextEsp32C3();  //se llama la funcion solo si el helper es true
      } else {
        I2CTVOCYSo2 = false;
        Serial.println("Error: I2C slave not responding");
      }


      stationTemperature = rtc.getTemperature();
      Serial.print("Station Temperature (RTC): ");
      Serial.print(stationTemperature, 2);
      Serial.println(" °C");

      if (photosenderOK == true) {
        Serial.println("request foto: OK Strikes: " + String(strikes));
      } else {
        Serial.println("request foto: NO , no recibi mensaje de la cam");
      }
      Serial.println("Strikes de transmision en httpinit: " + String(ModemStrikes));
      Serial.println("-----------------------");
      if (SDOK
          && RTCOK
          && ADC1
          && ADC2
          && ADC3
          && RS485METEO
          && RS485UV
          && I2CTVOCYSo2
          && PLANTOWER
          && Co2) {
        Serial.println("All OK");
        blinkGreenLed();
      } else {
        blinkYellowLed();
      }
      leyendoDatos = false;
    }
    yield();
  }

  // }///////// del antiguo wifi

  // —— SD save interval ——
  if (now - SaveMillis >= SAVE_INTERVAL_MS && requestedfoto == false) {
    SaveMillis = now;
    yield();
    savedSD = true;
    Serial.println("guardando SD");
    writeDataToCSV();
    Serial.println("-----------------------");
    savedSD = false;
  }

  // —— CAM save and Send interval ——
  if (now - SaveFotoMillis >= FOTO_INTERVAL_MS && photosenderOK == true) {
    yield();
    SaveFotoMillis = now;
    Serial.println("aqui va la funcion Sacar foto y mandar");
    requestedfoto = true;
    digitalWrite(CAM_POWER_PIN, HIGH);  // fileSerial.println("foto"); solo prendo la camara ya se espera el mensaje y el retry
    blinkOrangeLed();                   // naranja
    blinkOrangeLed();                   // naranja
    blinkOrangeLed();                   // naranja
    yield();
    sendAfterReceive = true;  // envío tras recibir
  }

  // —— SIGNAL CHECK interval ——
  if (now - lastNetworkUpdate >= networkInterval) {
    lastNetworkUpdate = now;
    sending = true;
    updateNetworkInfo();
    sending = false;
    yield();
  }
  // —— DATA SEND interval ——
  if (now - SendMillis >= SEND_INTERVAL_MS && requestedfoto == false) {
    //funcion mandar datos
    yield();
    SendMillis = now;
    sending = true;
    Serial.println("mandando datos");
    UpDATA();
    Serial.println("-----------------------");
    delay(50);
    sending = false;
    yield();
  }
}

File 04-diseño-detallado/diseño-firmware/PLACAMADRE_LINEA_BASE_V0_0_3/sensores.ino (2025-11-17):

void readAdcArraysold() {
  // ADS2 → adc2Raw[]
  adc2Raw[0] = ads2.readADC_SingleEnded(0);
  adc2Raw[1] = ads2.readADC_SingleEnded(1);
  adc2Raw[2] = ads2.readADC_SingleEnded(2);
  adc2Raw[3] = ads2.readADC_SingleEnded(3);

  // ADS1 → adc1Raw[]
  adc1Raw[0] = ads1.readADC_SingleEnded(0);
  adc1Raw[1] = ads1.readADC_SingleEnded(1);
  adc1Raw[2] = ads1.readADC_SingleEnded(2);
  adc1Raw[3] = ads1.readADC_SingleEnded(3);

  // ADS3 → adc3Raw[]
  adc3Raw[0] = ads3.readADC_SingleEnded(0);
  adc3Raw[1] = ads3.readADC_SingleEnded(1);
  adc3Raw[2] = ads3.readADC_SingleEnded(2);
  adc3Raw[3] = ads3.readADC_SingleEnded(3);
}
// funciones no bloqueantes en caso de error de sensores i2c
// --- I²C external sensor (TVOC + SO2) ---
// Helper: returns true si el dispositivo I2C responde en 'addr'
bool isDeviceConnected(uint8_t addr) {
  Wire.beginTransmission(addr);
  return (Wire.endTransmission() == 0);
}

//codigo revisando cada ADC
// Helper: attempt one ADS1115 read without blocking the bus if disconnected
// Try one ADS1115 read, return false if I²C fails
bool tryReadChannel(Adafruit_ADS1115 &adc, uint8_t address, uint8_t channel, float *out) {
  Wire.beginTransmission(address);
  if (Wire.endTransmission() != 0) {
    return false;  // device not responding
  }
  *out = static_cast<float>(adc.readADC_SingleEnded(channel));
  return true;
}

// Read ALL channels in one pass (blocks ≈1 ms por canal)
// Retries fallidos en la siguiente invocación
void readAllAdcChannelsOnce() {
  // ADS1 @ 0x48 → channels 0–3
  for (uint8_t ch = 0; ch < 4; ++ch) {
    if (!tryReadChannel(ads1, 0x48, ch, &adc1Raw[ch])) {
      Serial.printf("Error: ADS1 (0x48) ch %u failed\n", ch);
    }
  }

  // ADS2 @ 0x49 → channels 0–3
  for (uint8_t ch = 0; ch < 4; ++ch) {
    if (!tryReadChannel(ads2, 0x49, ch, &adc2Raw[ch])) {
      Serial.printf("Error: ADS2 (0x49) ch %u failed\n", ch);
    }
  }

  // ADS3 @ 0x4A → channels 0–1 (o 0–3 si los necesitas)
  for (uint8_t ch = 0; ch < 2; ++ch) {
    if (!tryReadChannel(ads3, 0x4A, ch, &adc3Raw[ch])) {
      Serial.printf("Error: ADS3 (0x4A) ch %u failed\n", ch);
    }
  }
}

void updateRawValues() {
  
  readAllAdcChannelsOnce();

  // Map array → globals
  adc2No2Op1Ch1Raw = adc2Raw[0];
  adc2No2Op2Ch2Raw = adc2Raw[1];
  adc2CoOp1Ch3Raw = adc2Raw[2];
  adc2CoOp2Ch4Raw = adc2Raw[3];

  adc1OxOp1Ch1Raw = adc1Raw[0];
  adc1OxOp2Ch2Raw = adc1Raw[1];
  adc1NoOp1Ch3Raw = adc1Raw[2];
  adc1NoOp2Ch4Raw = adc1Raw[3];

  adc3So2Op1Ch1Raw = adc3Raw[0];
  adc3So2Op2Ch2Raw = adc3Raw[1];
  // adc3XXOp1Ch3Raw = adc3Raw[2];
  // adc3XXOp2Ch4Raw = adc3Raw[3];
}

void printRawValues() {
  Serial.printf("ADC1 NO2  OP1/CH1 RAW: %.0f", adc2No2Op1Ch1Raw);
  Serial.printf(" ADC1 NO2  OP2/CH2 RAW: %.0f\n", adc2No2Op2Ch2Raw);
  Serial.printf("ADC1 CO   OP1/CH3 RAW: %.0f", adc2CoOp1Ch3Raw);
  Serial.printf(" ADC1 CO   OP2/CH4 RAW: %.0f\n", adc2CoOp2Ch4Raw);
  yield();

  Serial.printf("ADC2 OX   OP1/CH1 RAW: %.0f", adc1OxOp1Ch1Raw);
  Serial.printf(" ADC2 OX   OP2/CH2 RAW: %.0f\n", adc1OxOp2Ch2Raw);
  Serial.printf("ADC2 NO   OP1/CH3 RAW: %.0f", adc1NoOp1Ch3Raw);
  Serial.printf(" ADC2 NO   OP2/CH4 RAW: %.0f\n", adc1NoOp2Ch4Raw);
  yield();

  Serial.printf("ADC3 So2   OP1/CH1 RAW: %.0f", adc3So2Op1Ch1Raw);
  Serial.printf(" ADC3 So2   OP2/CH2 RAW: %.0f\n", adc3So2Op2Ch2Raw);
  // Serial.printf("ADC3 XX   OP1/CH3 RAW: %.0f", adc3XXOp1Ch3Raw);
  // Serial.printf(" ADC3 XX   OP2/CH4 RAW: %.0f\n", adc3XXOp2Ch4Raw);
  yield();
}
// modbus rs485
void preTransmission() {
  digitalWrite(DE_PIN, HIGH);
  digitalWrite(RE_PIN, HIGH);
}

void postTransmission() {
  digitalWrite(DE_PIN, LOW);
  digitalWrite(RE_PIN, LOW);
}
void readWindSensor() {
  modbus.begin(1, rs485Serial);  // ID = 1 estación meteorológica

  uint8_t result = modbus.readHoldingRegisters(0x01F4, 16);
  if (result == modbus.ku8MBSuccess) {
    windSpeed = modbus.getResponseBuffer(0) * 0.1;
    windStrength = modbus.getResponseBuffer(1);
    windDirection = modbus.getResponseBuffer(3);
    windHumidity = modbus.getResponseBuffer(4) * 0.1;
    windTemperature = (int16_t)modbus.getResponseBuffer(5) * 0.1;
    windPressure = modbus.getResponseBuffer(9) * 0.1;
    windRainfall = modbus.getResponseBuffer(13) * 0.1;
    windSolarIrradiance = modbus.getResponseBuffer(15);

    Serial.printf("[WIND] Speed: %.2f m/s  Strength: %u  Dir: %u deg\n", windSpeed, windStrength, windDirection);
    Serial.printf("[WIND] Hum: %.1f %%  Temp: %.1f C  Pres: %.1f kPa  Rain: %.1f mm  Solar: %.1f W/m2\n",
                  windHumidity, windTemperature, windPressure, windRainfall, windSolarIrradiance);
    RS485METEO = true;
  } else {
    Serial.printf("Modbus error (wind): 0x%02X\n", result);
    RS485METEO = false;
  }
}

void readUVSensor() {
  modbus.begin(2, rs485Serial);  // ID = 2 sensor UV

  uint8_t result = modbus.readHoldingRegisters(0x0000, 1);
  if (result == modbus.ku8MBSuccess) {
    uvIntensity_mWcm2 = modbus.getResponseBuffer(0) * 0.01f;
    Serial.printf("[UV] Intensity: %.2f mW/cm²\n", uvIntensity_mWcm2);
    RS485UV = true;
  } else {
    Serial.printf("Modbus error (UV intensity): %u\n", result);
    RS485UV = false;
  }

  result = modbus.readHoldingRegisters(0x0001, 1);
  if (result == modbus.ku8MBSuccess) {
    uvIndex = modbus.getResponseBuffer(0);
    Serial.printf("[UV] Index: %u\n", uvIndex);
    RS485UV = true;
  } else {
    Serial.printf("Modbus error (UV index): %u\n", result);
    RS485UV = false;
  }
}
void I2CextEsp32C3() {
  i2cBytes = Wire.requestFrom(I2C_SLAVE_ADDR, (uint8_t)32);
  if (i2cBytes == 0) {
    Serial.println("No I2C data received");
    I2CTVOCYSo2 = false;
  } else {
    // Clean payload (remove CR/LF)
    i2cBufLen = 0;
    while (Wire.available() && i2cBufLen < sizeof(i2cBuf) - 1) {
      char c = Wire.read();
      if (c != '\r' && c != '\n') {
        i2cBuf[i2cBufLen++] = c;
      }
      yield();
    }
    i2cBuf[i2cBufLen] = '\0';
    Serial.print("Clean I2C payload: ");
    Serial.println(i2cBuf);

    // Parse "<SO2_ppm>,<TVOC_ug/m3>"
    if (sscanf(i2cBuf, "%f,%hu", &so2Ppm, &tvocValue) == 2) {
      Serial.printf("Parsed SO2: %.3f raw  TVOC: %u ug/m3\n", so2Ppm, tvocValue);
      yield();
      I2CTVOCYSo2 = true;
    } else {
      Serial.println("I2C parsing error");
    }

    // Send ACK back
    Wire.beginTransmission(I2C_SLAVE_ADDR);
    Wire.write("OK");
    Wire.endTransmission();
    Serial.println("Sent I2C acknowledgment: OK");
  }
}
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

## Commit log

2025-11-11 Estructura inicial de Estación Multiparamétrica
2025-11-11 Update roles-responsabilidades.md
    pequeño update de equipo A. R.
2025-11-13 Agregar documentación de datasheets y reportes de laboratorio
2025-11-13 se genera documento y agregan comentarios para trabajar
2025-11-17 se actualiza el manual de mdicion de ruido
2025-11-17 Actualización del documento PDF de condiciones controladas se agrega archivo de latex y pdf recomendaciones de mejoras en hardwar diseño
2025-11-17 Add detailed documentation for high PSRR regulators and high-resolution ADCs for Alphasense gas sensors
    - Introduced a comprehensive LaTeX document outlining suitable linear regulators with high PSRR and low noise characteristics for powering Alphasense gas sensors.
    - Included specifications and pricing for various regulators such as Microchip MCP1754, Diodes Inc. AP7387, STMicroelectronics LDO40L, TI TPS7A4700, and Analog Devices LT3042.
    - Added a section on high-resolution ADCs (I²C/SPI) suitable for reading low-amplitude signals from Alphasense sensors, featuring options like Texas Instruments ADS1115, Microchip MCP3424, and TI/Waveshare ADS1256.
    - Provided references and links to datash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
2025-12-29 se sube pcb del adc directo al sensor
    [adcAlpha.brd, adcAlpha.sch]
2026-01-13 se sube pcb colector de señales actualizado
    [Bases_Aire_Sensors_v4.brd, Bases_Aire_Sensors_v4.sch]

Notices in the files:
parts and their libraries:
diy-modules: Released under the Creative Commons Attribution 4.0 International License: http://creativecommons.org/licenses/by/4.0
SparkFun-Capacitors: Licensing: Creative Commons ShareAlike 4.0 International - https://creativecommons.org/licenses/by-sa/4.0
